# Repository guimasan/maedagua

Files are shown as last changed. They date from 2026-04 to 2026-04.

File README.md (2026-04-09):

# IARA V1 — Monitoramento de Qualidade da Água (Arduino Uno)

Projeto para aquisição de dados de **temperatura** e **TDS/condutividade estimada**, com transmissão serial, painel local e página pública para visualização em tempo real.

## Visão geral

O IARA V1 realiza:

- leitura de temperatura com **DS18B20**
- leitura analógica de **TDS** em `A1`
- exibição local em **OLED SSD1306 I2C (128x64)**
- envio contínuo de telemetria via **USB Serial**

O repositório inclui firmware, backend de painel e dashboard web para uso local e publicação.

## Estrutura do repositório

- `firmware/iara_arduino_uno_v1.ino` — firmware do Arduino Uno
- `_painel_iot_server/` — backend + dashboards locais
- `docs/index.html` — dashboard público (GitHub Pages)
- `docs/USO_RAPIDO.md` — guia curto de operação
- `tools/calibrar_tds.py` — calibração rápida via serial
- `tools/diagnostico_leituras.py` — diagnóstico comparativo de modos

## Arquitetura de dados

1. O Arduino coleta dados dos sensores.
2. A telemetria é enviada pela serial (`115200`).
3. O bridge (`_painel_iot_server/bridge_arduino.py`) converte e publica para a API.
4. Dashboards consomem API/WS para visualização em tempo real e histórico.

Exemplo de payload serial:

```text
DEVICE=iara-uno-0001;SEQ=1;TS_MS=1034;TEMP_C=25.19;TDS_PPM=131;TDS_ADC=287;TDS_V=1.404;TEMP_OK=1;TDS_OK=1;FW=1.0.0
```

## Equipamentos e sensores utilizados

- **Microcontrolador:** Arduino Uno (ATmega328P)
- **Temperatura:** DS18B20 (OneWire)
- **TDS/EC:** módulo TDS analógico compatível com entrada ADC do Uno
- **Display:** OLED SSD1306 I2C 128x64 (`0x3C`)
- **Conexão host:** USB serial

## Ligações elétricas (padrão do projeto)

- **DS18B20:** `D3`, `5V`, `GND`
- **TDS analógico:** `A1`, `5V`, `GND`
- **OLED SSD1306:** `SDA(A4)`, `SCL(A5)`, `5V`, `GND`

## Medidas, faixas e interpretação

### Temperatura (DS18B20)

- resolução configurável pelo sensor: 9–12 bits
- precisão típica de referência: aproximadamente $\pm 0.5\,^{\circ}C$ na faixa central de operação (ver datasheet)
- saída no projeto: `TEMP_C`

### TDS/EC (módulo analógico)

- leitura bruta no ADC de 10 bits do Uno (`0..1023`): `TDS_ADC`
- tensão estimada: `TDS_V`
- concentração estimada: `TDS_PPM`
- valor bruto antes de ganho de calibração: `TDS_RAW_PPM`

> Observação: TDS depende de temperatura, tipo de sonda, circuito e solução de referência. Tratar os valores como **medição estimada**, com calibração periódica.

## Calibração TDS

Campos publicados:

- `CAL` — estado da calibração
- `CAL_GAIN` — ganho aplicado
- `TDS_RAW_PPM` — base sem ganho

Estados de `CAL`:

- `0`: idle
- `1`: aguardando referência
- `2`: aplicado e não salvo
- `3`: salvo em EEPROM

Comandos serial:

- `CAL=ON`
- `CAL=APPLY:<ppm>`
- `CAL=SAVE`
- `CAL=RESET`
- `CAL=OFF`
- `CAL?`

Referência comum de condutividade:

- solução: **1413 µS/cm**
- escala 500: $ppm = EC \times 0.5$
- resultado: $1413 \times 0.5 = 706.5\,ppm$

Aplicação típica: `CAL=APPLY:706.5` seguido de `CAL=SAVE`.

## Modos de diagnóstico de leitura

Comandos para avaliar impacto de OLED e sequência de amostragem:

- `MODE=0` normal
- `MODE=1` pausa OLED durante leitura
- `MODE=2` OLED desligada durante leitura
- `MODE=3` OLED sempre desligada
- `MODE=4` leitura alternada por sensor
- consulta: `MODE?` ou `STATUS`

## Bibliotecas Arduino

- `OneWire`
- `DallasTemperature`
- `Adafruit GFX Library`
- `Adafruit SSD1306`

## Operação rápida

1. Gravar `firmware/iara_arduino_uno_v1.ino` no Arduino Uno.
2. Abrir monitor serial em `115200`.
3. Validar chegada de telemetria.
4. Opcional: executar scripts em `tools/` para diagnóstico/calibração.
5. Subir backend em `_painel_iot_server` para dashboard local e integração web.

## Dashboard público (GitHub Pages)

`docs/index.html` fornece:

- visualização em tempo real
- histórico cronológico
- detecção automática de variáveis
- seleção de endpoint da API

Para publicar:

1. Ativar GitHub Pages apontando para `main/docs`.
2. Abrir a página publicada.
3. Configurar a URL da API (preferencialmente HTTPS).

## Boas práticas de medição

- Aguarde estabilização térmica da amostra antes de registrar.
- Evite encostar a sonda nas paredes do recipiente.
- Faça agitação leve e padronizada da amostra.
- Registre temperatura junto com TDS para comparação entre coletas.
- Recalibre periodicamente com solução padrão conhecida.

## Referências técnicas

- Arduino Uno Rev3: https://docs.arduino.cc/hardware/uno-rev3
- ATmega328P (microcontrolador do Uno): https://www.microchip.com/en-us/product/ATmega328P
- DS18B20 (Maxim/Analog): https://www.analog.com/en/products/ds18b20.html
- Biblioteca DallasTemperature: https://github.com/milesburton/Arduino-Temperature-Control-Library
- Biblioteca OneWire (Paul Stoffregen): https://github.com/PaulStoffregen/OneWire
- Adafruit SSD1306: https://github.com/adafruit/Adafruit_SSD1306
- Adafruit GFX: https://github.com/adafruit/Adafruit-GFX-Library

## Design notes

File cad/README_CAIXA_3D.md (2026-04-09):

# Caixa 3D — IARA V1

Este diretório contém um modelo paramétrico em OpenSCAD para a caixa do sistema IARA V1.

## Arquivo

- `caixa_iara_v1.scad`

## Arquivos prontos para impressão

Já renderizados neste projeto:

- `cad/stl/caixa_iara_v1_base.stl`
- `cad/stl/caixa_iara_v1_tampa.stl`

Esses arquivos podem ser importados direto no slicer da sua impressora.

## Componentes previstos

- Arduino Uno
- Módulo TDS Keyestudio v1.0 (dimensões aproximadas)
- OLED 0.96" I2C
- Saída lateral para cabo do TDS
- Saída lateral para cabo do sensor de temperatura
- Recortes para USB-B e jack DC do Uno

## Saída do display (OLED) — revisão aplicada

A janela do display fica na **tampa superior** e agora é totalmente ajustável por parâmetros:

- `oled_margin_top` → distância da borda superior da tampa até o centro da janela
- `oled_offset_x` → deslocamento horizontal da janela

Também foram incluídos:

- postes internos para fixação do OLED (`lid_oled_posts`)
- canal para passagem do cabo do OLED (`oled_cable_notch_*`)

Se quiser mover a janela para alinhar exatamente ao seu módulo, ajuste esses dois parâmetros e gere apenas a tampa (`part = "lid"`) para teste rápido.

## Saídas dos cabos dos sensores (TDS e temperatura)

As saídas ficam na **lateral direita da base**.

Dimensões aplicadas no modelo:

- TDS (conector): retangular `5 x 7 mm` + folga
- Temperatura (cabo): circular `4 mm` + folga

Para visualizar facilmente no OpenSCAD, use:

- `part = "base"` ou `part = "assembled"`
- `show_cable_helpers = true`

Com isso, o modelo mostra guias verdes transparentes indicando o caminho dos furos. Essas guias são somente preview e **não entram no STL**.

## Como gerar STL

No OpenSCAD:

1. Abra `caixa_iara_v1.scad`
2. Ajuste `part` para:
   - `"base"` para exportar a base
   - `"lid"` para exportar a tampa
3. Renderize (`F6`)
4. Exporte STL

## Configuração inicial de impressão (FDM)

- Bico: 0.4 mm
- Altura de camada: 0.2 mm
- Paredes: 3 linhas
- Infill: 20–30%
- Material sugerido:
  - PLA para protótipo rápido
  - PETG para uso em ambiente úmido/externo
- Suportes: normalmente não necessários

## Perfil sugerido — Creality Hi + PETG Premium

Configuração inicial segura para começar (ajuste fino depois do primeiro teste):

- Bico: `0.4 mm`
- Altura de camada: `0.20 mm`
- Largura de linha: `0.42 mm`
- Paredes: `3`
- Top/Bottom: `5` camadas
- Infill: `25%` (Gyroid ou Grid)
- Temperatura do bico:
   - 1ª camada: `245 °C`
   - demais: `240 °C`
- Mesa:
   - 1ª camada: `80 °C`
   - demais: `75 °C`
- Ventoinha:
   - 1ª camada: `0%`
   - demais: `20–35%`
- Velocidade:
   - perímetro externo: `35 mm/s`
   - perímetro interno: `55 mm/s`
   - preenchimento: `70 mm/s`
- Retração (direct drive):
   - distância: `0.8 mm`
   - velocidade: `35 mm/s`
- Brim: `6 mm` (recomendado para PETG)

### Orientação das peças no slicer

- `caixa_iara_v1_base.stl`: imprimir com o fundo plano na mesa.
- `caixa_iara_v1_tampa.stl`: imprimir com a face externa da tampa voltada para a mesa.

### Material

Para PETG Premium, limpar mesa e aplicar adesão leve (cola bastão/spray apropriado) ajuda a evitar excesso de aderência na remoção.

## Parafusos recomendados

- Fixação de placas: parafuso M3 (autoatarraxante leve ou porca M3, conforme ajuste)
- Fechamento da tampa: M3 x 8 a M3 x 12

## Ajustes esperados (importante)

As dimensões do módulo TDS e do OLED podem variar entre lotes/fabricantes. Recomenda-se:

1. Medir sua placa real com paquímetro
2. Ajustar no SCAD os parâmetros:
   - `tds_x`, `tds_y`, `tds_holes`
   - `oled_*` (janela, furos, postes e canal de cabo)
3. Imprimir um teste rápido da tampa para validar a janela do OLED

## Observação

O modelo foi feito para ser fácil de ajustar em campo e prioriza montagem prática.

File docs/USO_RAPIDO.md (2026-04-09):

# Uso rápido

## Ligar

- DS18B20 no pino D3
- TDS no pino A1
- OLED I2C 128x64 em SDA(A4) e SCL(A5)
- Arduino Uno no USB

## Bibliotecas necessárias

- OneWire
- DallasTemperature
- Adafruit GFX Library
- Adafruit SSD1306

## Enviar o código

Abra:

- `firmware/iara_arduino_uno_v1.ino`

Depois envie para a placa.

## Ver os dados

Abra o monitor serial em:

- `115200`

Exemplo:

```text
DEVICE=iara-uno-0001;SEQ=1;TS_MS=1034;TEMP_C=25.19;TDS_PPM=131;TDS_ADC=287;TDS_V=1.404;TEMP_OK=1;TDS_OK=1;FW=1.0.0
```

Agora o payload inclui também:

- `TDS_RAW_PPM`
- `CAL`
- `CAL_GAIN`
- `DISP`

## Calibração rápida no Monitor Serial

1. Abra o Monitor Serial em `115200`
2. Envie `CAL=ON`
3. Com a sonda em solução padrão, envie o valor equivalente em ppm.
   - Exemplo para **1413 µS/cm** no padrão 500-scale: `CAL=APPLY:706.5`
4. Se estiver bom, envie `CAL=SAVE`
5. Para conferir, envie `CAL?`

## O que o notebook faz

Seu webapp pode:

- ler a porta serial
- sincronizar os dados
- salvar logs
- mostrar histórico
- fazer gráficos e alertas

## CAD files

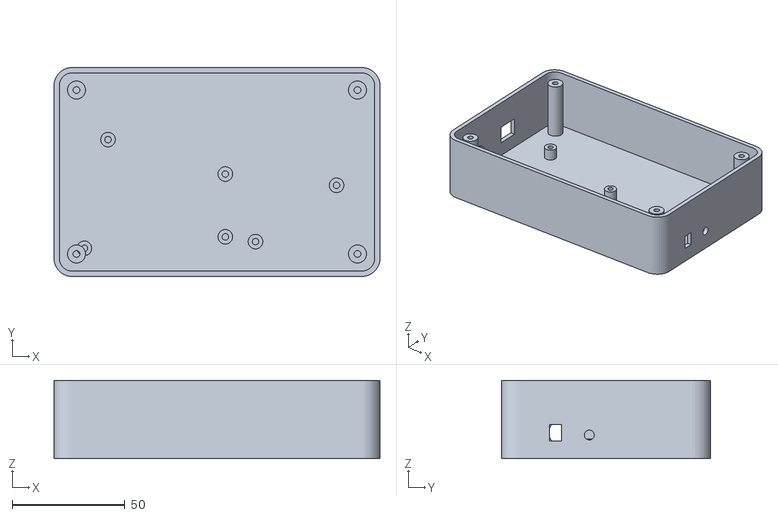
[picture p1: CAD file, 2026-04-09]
cad/stl/caixa_iara_v1_base.stl
144.8 x 92.8 x 34.8

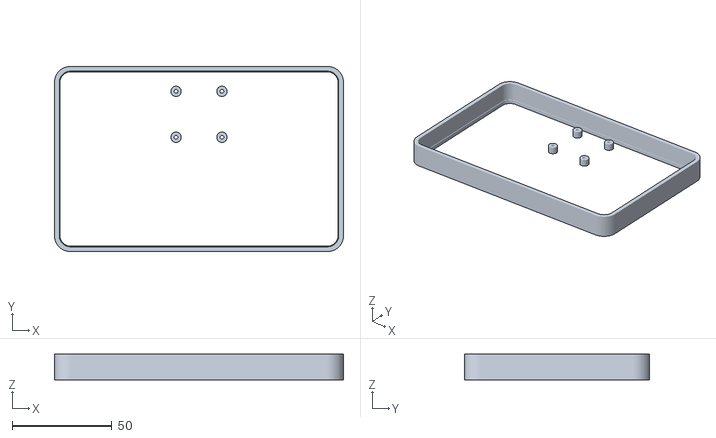
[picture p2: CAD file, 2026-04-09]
cad/stl/caixa_iara_v1_tampa.stl
144.8 x 92.8 x 13.0

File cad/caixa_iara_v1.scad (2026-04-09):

// IARA V1 - Caixa paramétrica (OpenSCAD)
// Componentes: Arduino Uno, módulo TDS Keyestudio v1.0, OLED 0.96" I2C
// Exportar com: part = "base" ou part = "lid"

$fn = 48;

// =====================
// Seleção de peça
// =====================
part = "assembled"; // "base", "lid", "assembled"
show_cable_helpers = true; // true = mostra guias visuais das saídas de cabo

// =====================
// Dimensões gerais (mm)
// =====================
wall = 2.4;
bottom = 2.8;
lid_thickness = 2.4;
clearance = 0.35;
corner_r = 8;

inner_x = 140;
inner_y = 88;
inner_z = 32; // altura útil interna da base

outer_x = inner_x + wall * 2;
outer_y = inner_y + wall * 2;
base_h = bottom + inner_z;
lid_h = 13;

// =====================
// Arduino Uno R3 (aprox.)
// =====================
uno_x = 68.6;
uno_y = 53.4;
uno_h = 14; // folga para componentes + headers
standoff_d = 6.5;
standoff_h = 6;
standoff_hole_d = 2.9; // para parafuso M3 autoatarraxante leve

// Furação aproximada (referência no canto da placa)
uno_holes = [
    [3.5, 2.5],
    [66.1, 7.6],
    [66.1, 35.5],
    [14.0, 50.8]
];

// posição da placa dentro da caixa
uno_pos = [10, 10, bottom];

// recortes laterais para USB-B e jack DC (lado esquerdo da caixa)
usb_cut = [13, 11.5, 9.5]; // x(profundidade), y(largura), z(altura)
usb_cut_pos = [0, uno_pos[1] + 36, 10.5];

jack_cut_d = 11;
jack_cut_pos = [0, uno_pos[1] + 16.5, 11.5];

// =====================
// Módulo TDS Keyestudio v1.0 (aprox.)
// =====================
tds_x = 43;
tds_y = 32;
tds_pos = [86, 12, bottom];
tds_holes = [
    [3.5, 3.5],
    [39.5, 28.5]
];

// =====================
// OLED 0.96" (módulo I2C 4 pinos)
// =====================
oled_board_x = 27.5;
oled_board_y = 27.5;
oled_hole_pitch_x = 23;
oled_hole_pitch_y = 23;
oled_screen_x = 23.5;
oled_screen_y = 13.5;

// Saída do display (janela) na tampa:
// - oled_margin_top maior = janela mais para baixo
// - oled_offset_x positivo = desloca para a direita
oled_margin_top = 24;
oled_offset_x = 0;
oled_center = [outer_x / 2 + oled_offset_x, outer_y - oled_margin_top];

// Ajustes de montagem da placa OLED na tampa
oled_hole_d = 2.4;
oled_post_d = 5.2;
oled_post_h = 4.0;
oled_post_hole_d = 1.9; // para parafuso M2/M2.2

// Canal para passagem dos fios do OLED (lado superior da tampa)
oled_cable_notch_w = 8;
oled_cable_notch_h = 4;

echo("OLED center XY:", oled_center);
echo("Ajuste saída display: oled_margin_top / oled_offset_x");

// =====================
// Saídas de cabo
// =====================
// Lado direito da base
cable_fit_clearance = 0.4; // folga geral para montagem/impressão

// TDS: conector retangular informado (5 x 7 mm)
cable_tds_w = 5 + cable_fit_clearance;
cable_tds_h = 7 + cable_fit_clearance;

// Temperatura: cabo circular de 4 mm
cable_temp_d = 4 + cable_fit_clearance;
cable_cut_depth = wall + 2.2; // profundidade para atravessar a parede com folga

// Nota: o eixo do cilindro está no +X após rotate([0,90,0]), então iniciamos em
// outer_x - cable_cut_depth para garantir corte completo na lateral direita.
// Para o TDS retangular usamos a mesma referência de centro em Y/Z
cable_tds_center_y = 24;
cable_tds_center_z = 11.5;
cable_tds_pos = [outer_x - cable_cut_depth, cable_tds_center_y - cable_tds_w / 2, cable_tds_center_z - cable_tds_h / 2];
cable_temp_pos = [outer_x - cable_cut_depth, 39, 10.5];

// =====================
// Parafusos da tampa
// =====================
post_d = 8;
post_hole_d = 3.0;
post_core_h = inner_z - 2;

post_xy = [
    [10, 10],
    [outer_x - 10, 10],
    [outer_x - 10, outer_y - 10],
    [10, outer_y - 10]
];

module rounded_box(x, y, z, r) {
    hull() {
        for (ix = [r, x - r])
            for (iy = [r, y - r])
                translate([ix, iy, 0]) cylinder(h = z, r = r);
    }
}

module shell_base() {
    difference() {
        rounded_box(outer_x, outer_y, base_h, corner_r);
        translate([wall, wall, bottom])
            rounded_box(inner_x, inner_y, inner_z + 0.2, max(corner_r - wall, 1));
    }
}

module lid_shell() {
    difference() {
        rounded_box(outer_x, outer_y, lid_h, corner_r);

        // cavidade da tampa
        translate([wall, wall, lid_thickness])
            rounded_box(inner_x, inner_y, lid_h, max(corner_r - wall, 1));

        // aba de encaixe
        translate([wall + clearance, wall + clearance, 0])
            rounded_box(inner_x - 2 * clearance, inner_y - 2 * clearance, 8, max(corner_r - wall - clearance, 1));

        // remover centro da aba
        translate([wall + 2.2, wall + 2.2, 0])
            rounded_box(inner_x - 4.4, inner_y - 4.4, 8.1, max(corner_r - wall - 2.2, 1));
    }
}

module board_standoffs(origin, holes) {
    for (h = holes) {
        translate([origin[0] + h[0], origin[1] + h[1], origin[2]])
            difference() {
                cylinder(h = standoff_h, d = standoff_d);
                translate([0, 0, -0.1]) cylinder(h = standoff_h + 0.2, d = standoff_hole_d);
            }
    }
}

module lid_posts_for_screws() {
    for (p = post_xy) {
        translate([p[0], p[1], bottom])
            difference() {
                cylinder(h = post_core_h, d = post_d);
                translate([0, 0, -0.1]) cylinder(h = post_core_h + 0.2, d = post_hole_d);
            }
    }
}

module cable_holes() {
    // TDS
    translate(cable_tds_pos)
        cube([cable_cut_depth, cable_tds_w, cable_tds_h]);

    // Temperatura
    translate(cable_temp_pos)
        rotate([0, 90, 0]) cylinder(h = cable_cut_depth, d = cable_temp_d);
}

module cable_holes_helper() {
    if (show_cable_helpers) {
        // Preview only (%): visível no editor, não exporta para STL
        %color([0.2, 0.9, 0.3, 0.45])
            translate(cable_tds_pos)
                cube([cable_cut_depth, cable_tds_w, cable_tds_h]);
        %color([0.2, 0.9, 0.3, 0.45])
            translate(cable_temp_pos)
                rotate([0, 90, 0]) cylinder(h = cable_cut_depth, d = cable_temp_d);
    }
}

module uno_side_ports() {
    // USB-B
    translate([usb_cut_pos[0] - 0.5, usb_cut_pos[1], usb_cut_pos[2]])
        cube([usb_cut[0] + 1, usb_cut[1], usb_cut[2]]);

    // Jack DC
    translate([jack_cut_pos[0] - 0.5, jack_cut_pos[1], jack_cut_pos[2]])
        rotate([0, 90, 0]) cylinder(h = wall + 1.5, d = jack_cut_d);
}

module lid_oled_window_and_holes() {
    // Janela do display
    translate([oled_center[0] - oled_screen_x / 2, oled_center[1] - oled_screen_y / 2, -0.2])
        cube([oled_screen_x, oled_screen_y, lid_thickness + 0.6]);

    // Furos da placa OLED
    for (sx = [-oled_hole_pitch_x / 2, oled_hole_pitch_x / 2])
        for (sy = [-oled_hole_pitch_y / 2, oled_hole_pitch_y / 2])
            translate([oled_center[0] + sx, oled_center[1] + sy, -0.2])
                cylinder(h = lid_thickness + 1.2, d = oled_hole_d);

    // Canal de saída do cabo do OLED (da região dos pinos para dentro da caixa)
    translate([oled_center[0] - oled_cable_notch_w / 2, oled_center[1] + oled_hole_pitch_y / 2 - 1, -0.2])
        cube([oled_cable_notch_w, oled_cable_notch_h, lid_thickness + 0.8]);
}

module lid_oled_posts() {
    // Postes de apoio/fixação da placa OLED na face interna da tampa
    for (sx = [-oled_hole_pitch_x / 2, oled_hole_pitch_x / 2])
        for (sy = [-oled_hole_pitch_y / 2, oled_hole_pitch_y / 2])
            translate([oled_center[0] + sx, oled_center[1] + sy, lid_thickness])
                difference() {
                    cylinder(h = oled_post_h, d = oled_post_d);
                    translate([0, 0, -0.1]) cylinder(h = oled_post_h + 0.2, d = oled_post_hole_d);
                }
}

module lid_screw_holes() {
    for (p = post_xy) {
        translate([p[0], p[1], -0.2])
            cylinder(h = lid_h + 0.4, d = 3.4);

        // rebaixo para cabeça do parafuso
        translate([p[0], p[1], lid_h - 2.2])
            cylinder(h = 2.5, d = 6.2);
    }
}

module base_part() {
    difference() {
        shell_base();
        cable_holes();
        uno_side_ports();
    }

    // Standoffs Arduino
    board_standoffs(uno_pos, uno_holes);

    // Standoffs TDS
    board_standoffs(tds_pos, tds_holes);

    // Postes para parafusos da tampa
    lid_posts_for_screws();
}

module lid_part() {
    union() {
        difference() {
            lid_shell();
            lid_oled_window_and_holes();
            lid_screw_holes();
        }
        lid_oled_posts();
    }
}

if (part == "base") {
    base_part();
    cable_holes_helper();
}

if (part == "lid") {
    lid_part();
}

if (part == "assembled") {
    color("#1f2937") base_part();
    cable_holes_helper();
    translate([0, 0, base_h + 0.2]) color("#334155") lid_part();
}

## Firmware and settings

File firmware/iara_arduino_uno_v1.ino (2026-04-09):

/*
  MaeDagua - Arduino Uno V1

  Função deste sketch:
  - ler temperatura no DS18B20 (D3)
  - ler TDS no A1
  - enviar dados pela USB Serial

  O notebook/webapp pode ler essa serial,
  sincronizar e guardar logs quando quiser.

  Formato enviado:
  DEVICE=iara-uno-0001;SEQ=1;TS_MS=1034;TEMP_C=25.19;TDS_PPM=131;TDS_ADC=287;TDS_V=1.404;TEMP_OK=1;TDS_OK=1;FW=1.0.0
*/

#include <OneWire.h>
#include <DallasTemperature.h>
#include <Wire.h>
#include <Adafruit_GFX.h>
#include <Adafruit_SSD1306.h>
#include <EEPROM.h>

const int PIN_TEMP_SENSOR = 3;
const int PIN_TDS_SENSOR = A1;
const char* DEVICE_ID = "iara-uno-0001";
const char* FW_VERSION = "1.5.0";

const int OLED_WIDTH = 128;
const int OLED_HEIGHT = 64;
const int OLED_RESET_PIN = -1;
const uint8_t OLED_I2C_ADDR = 0x3C;

OneWire oneWireBus(PIN_TEMP_SENSOR);
DallasTemperature temperatureSensors(&oneWireBus);
Adafruit_SSD1306 oled(OLED_WIDTH, OLED_HEIGHT, &Wire, OLED_RESET_PIN);

const unsigned long SEND_INTERVAL_MS = 1000;
unsigned long lastSendAtMs = 0;
unsigned long packetSequence = 0;
const unsigned long OLED_PAGE_INTERVAL_MS = 5000;
const unsigned long OLED_TRANSITION_MS = 900;
const unsigned long OLED_REFRESH_MS = 80;
const int SERIAL_CMD_BUFFER_SIZE = 32;

const float TDS_CALIBRATION_FACTOR = 0.5;
const int TDS_SAMPLES = 20;
const int TDS_SAMPLE_DELAY_MS = 2;
const float TDS_MIN_RAW_PPM_FOR_CAL = 5.0;

const int EEPROM_ADDR_MAGIC = 0;
const int EEPROM_ADDR_TDS_GAIN = EEPROM_ADDR_MAGIC + sizeof(uint16_t);
const uint16_t EEPROM_CAL_MAGIC = 0xC411;

bool isOledReady = false;

enum CalState {
  CAL_STATE_IDLE = 0,
  CAL_STATE_WAIT_REFERENCE = 1,
  CAL_STATE_APPLIED_NOT_SAVED = 2,
  CAL_STATE_SAVED = 3
};

uint8_t calibrationState = CAL_STATE_IDLE;
float tdsCalibrationGain = 1.0;

enum ReadMode {
  READ_MODE_NORMAL = 0,
  READ_MODE_PAUSE_OLED_DURING_READ = 1,
  READ_MODE_DISPLAY_OFF_DURING_READ = 2,
  READ_MODE_OLED_DISABLED = 3,
  READ_MODE_ALTERNATE_SENSORS = 4,
  READ_MODE_COUNT
};

uint8_t currentReadMode = READ_MODE_NORMAL;
bool isSensorReadInProgress = false;
bool nextAlternateReadIsTemp = true;
char serialCmdBuffer[SERIAL_CMD_BUFFER_SIZE];
uint8_t serialCmdPos = 0;

enum DisplayMode {
  DISPLAY_MODE_ROTATING = 0,
  DISPLAY_MODE_SINGLE_SCREEN = 1
};

uint8_t currentDisplayMode = DISPLAY_MODE_ROTATING;

enum OledPage {
  OLED_PAGE_TEMP = 0,
  OLED_PAGE_TDS_PPM,
  OLED_PAGE_TDS_VOLTAGE,
  OLED_PAGE_FISH,
  OLED_PAGE_COUNT
};

uint8_t currentOledPage = OLED_PAGE_TEMP;
unsigned long oledPageStartedAtMs = 0;
unsigned long lastOledRefreshAtMs = 0;
bool isTransitionActive = false;
unsigned long transitionStartedAtMs = 0;

bool latestTempOk = false;
float latestTempC = NAN;
int latestTdsAdc = 0;
float latestRawTdsPpm = 0;
float latestTdsVoltage = 0;
float latestTdsPpm = 0;
bool hasSensorData = false;
float lastValidTempC = 0;
bool hasLastValidTemp = false;
bool tempSampledThisCycle = false;
bool tdsSampledThisCycle = false;

float readTemperatureCelsius(bool &ok) {
  temperatureSensors.requestTemperatures();
  float value = temperatureSensors.getTempCByIndex(0);
  ok = (value != DEVICE_DISCONNECTED_C);
  return ok ? value : NAN;
}

int readTdsMedianAdc() {
  int samples[TDS_SAMPLES];

  for (int i = 0; i < TDS_SAMPLES; i++) {
    samples[i] = analogRead(PIN_TDS_SENSOR);
    delay(TDS_SAMPLE_DELAY_MS);
  }

  for (int i = 0; i < TDS_SAMPLES - 1; i++) {
    for (int j = i + 1; j < TDS_SAMPLES; j++) {
      if (samples[j] < samples[i]) {
        int aux = samples[i];
        samples[i] = samples[j];
        samples[j] = aux;
      }
    }
  }

  return samples[TDS_SAMPLES / 2];
}

float convertAdcToVoltage(int adc) {
  return adc * (5.0 / 1023.0);
}

float convertAdcToTdsPpm(int adc) {
  float voltage = convertAdcToVoltage(adc);
  float tds = (voltage - 0.15) * TDS_CALIBRATION_FACTOR * 1000.0;
  if (tds < 0) tds = 0;
  return tds;
}

void loadCalibrationFromEeprom() {
  uint16_t magic = 0;
  float gain = 1.0;
  EEPROM.get(EEPROM_ADDR_MAGIC, magic);
  EEPROM.get(EEPROM_ADDR_TDS_GAIN, gain);

  if (magic == EEPROM_CAL_MAGIC && gain > 0.05 && gain < 20.0) {
    tdsCalibrationGain = gain;
    calibrationState = CAL_STATE_SAVED;
  } else {
    tdsCalibrationGain = 1.0;
    calibrationState = CAL_STATE_IDLE;
  }
}

void saveCalibrationToEeprom() {
  EEPROM.put(EEPROM_ADDR_MAGIC, EEPROM_CAL_MAGIC);
  EEPROM.put(EEPROM_ADDR_TDS_GAIN, tdsCalibrationGain);
  calibrationState = CAL_STATE_SAVED;
}

void resetCalibration() {
  tdsCalibrationGain = 1.0;
  EEPROM.put(EEPROM_ADDR_MAGIC, (uint16_t)0);
  EEPROM.put(EEPROM_ADDR_TDS_GAIN, tdsCalibrationGain);
  calibrationState = CAL_STATE_IDLE;
}

void setOledPower(bool on) {
  if (!isOledReady) {
    return;
  }
  oled.ssd1306_command(on ? SSD1306_DISPLAYON : SSD1306_DISPLAYOFF);
}

void applyReadMode(uint8_t mode) {
  if (mode >= READ_MODE_COUNT) {
    return;
  }

  currentReadMode = mode;
  nextAlternateReadIsTemp = true;

  if (currentReadMode == READ_MODE_OLED_DISABLED) {
    setOledPower(false);
  } else {
    setOledPower(true);
    oledPageStartedAtMs = millis();
    transitionStartedAtMs = millis();
    isTransitionActive = false;
  }

  Serial.print(F("MODE_SET="));
  Serial.println(currentReadMode);
}

void applyDisplayMode(uint8_t mode) {
  if (mode > DISPLAY_MODE_SINGLE_SCREEN) {
    return;
  }

  currentDisplayMode = mode;
  oledPageStartedAtMs = millis();
  transitionStartedAtMs = millis();
  isTransitionActive = false;

  Serial.print(F("DISP_SET="));
  Serial.println(currentDisplayMode);
}

void printCalibrationStatus() {
  Serial.print(F("CAL="));
  Serial.print(calibrationState);
  Serial.print(F(";CAL_GAIN="));
  Serial.println(tdsCalibrationGain, 5);
}

void processSerialCommand(const char* cmdRaw) {
  if (strncmp(cmdRaw, "MODE=", 5) == 0) {
    int mode = atoi(cmdRaw + 5);
    if (mode >= 0 && mode < READ_MODE_COUNT) {
      applyReadMode((uint8_t)mode);
    } else {
      Serial.println(F("ERR=MODE_INVALID"));
    }
    return;
  }

  if (strncmp(cmdRaw, "DISP=", 5) == 0) {
    int mode = atoi(cmdRaw + 5);
    if (mode >= 0 && mode <= DISPLAY_MODE_SINGLE_SCREEN) {
      applyDisplayMode((uint8_t)mode);
    } else {
      Serial.println(F("ERR=DISP_INVALID"));
    }
    return;
  }

  if (strcmp(cmdRaw, "CAL=ON") == 0) {
    calibrationState = CAL_STATE_WAIT_REFERENCE;
    Serial.println(F("CAL_MODE=WAIT_REFERENCE"));
    printCalibrationStatus();
    return;
  }

  if (strcmp(cmdRaw, "CAL=OFF") == 0) {
    calibrationState = CAL_STATE_IDLE;
    Serial.println(F("CAL_MODE=OFF"));
    printCalibrationStatus();
    return;
  }

  if (strncmp(cmdRaw, "CAL=APPLY:", 10) == 0) {
    float referencePpm = atof(cmdRaw + 10);
    if (referencePpm <= 0) {
      Serial.println(F("ERR=CAL_REFERENCE_INVALID"));
      return;
    }
    if (latestRawTdsPpm < TDS_MIN_RAW_PPM_FOR_CAL) {
      Serial.println(F("ERR=CAL_RAW_TOO_LOW"));
      return;
    }

    tdsCalibrationGain = referencePpm / latestRawTdsPpm;
    if (tdsCalibrationGain < 0.05 || tdsCalibrationGain > 20.0) {
      Serial.println(F("ERR=CAL_GAIN_OUT_OF_RANGE"));
      tdsCalibrationGain = 1.0;
      calibrationState = CAL_STATE_IDLE;
      return;
    }

    calibrationState = CAL_STATE_APPLIED_NOT_SAVED;
    Serial.print(F("CAL_APPLIED_REF="));
    Serial.println(referencePpm, 2);
    printCalibrationStatus();
    return;
  }

  if (strcmp(cmdRaw, "CAL=SAVE") == 0) {
    saveCalibrationToEeprom();
    Serial.println(F("CAL_SAVED=1"));
    printCalibrationStatus();
    return;
  }

  if (strcmp(cmdRaw, "CAL=RESET") == 0) {
    resetCalibration();
    Serial.println(F("CAL_RESET=1"));
    printCalibrationStatus();
    return;
  }

  if (strcmp(cmdRaw, "MODE?") == 0 || strcmp(cmdRaw, "STATUS") == 0) {
    Serial.print(F("MODE="));
    Serial.println(currentReadMode);
    Serial.print(F("DISP="));
    Serial.println(currentDisplayMode);
    printCalibrationStatus();
    return;
  }

  if (strcmp(cmdRaw, "DISP?") == 0) {
    Serial.print(F("DISP="));
    Serial.println(currentDisplayMode);
    return;
  }

  if (strcmp(cmdRaw, "CAL?") == 0) {
    printCalibrationStatus();
    return;
  }

  if (strcmp(cmdRaw, "HELP") == 0) {
    Serial.println(F("CMD: MODE=0..4 | DISP=0..1 | CAL=ON|OFF|APPLY:ppm|SAVE|RESET | MODE? | DISP? | CAL? | STATUS | HELP"));
    return;
  }

  Serial.println(F("ERR=CMD_UNKNOWN"));
}

void handleSerialCommands() {
  while (Serial.available() > 0) {
    char c = (char)Serial.read();

    if (c == '\r') {
      continue;
    }

    if (c == '\n') {
      if (serialCmdPos > 0) {
        serialCmdBuffer[serialCmdPos] = '\0';
        processSerialCommand(serialCmdBuffer);
        serialCmdPos = 0;
      }
      continue;
    }

    if (serialCmdPos < SERIAL_CMD_BUFFER_SIZE - 1) {
      serialCmdBuffer[serialCmdPos++] = c;
    }
  }
}

void formatFloatValue(char* out, size_t outSize, float value, uint8_t decimals, const char* suffix) {
  char number[16];
  dtostrf(value, 0, decimals, number);
  snprintf(out, outSize, "%s%s", number, suffix);
}

void drawCenteredText(const char* text, int y, uint8_t size) {
  int16_t x1, y1;
  uint16_t width, height;
  oled.setTextSize(size);
  oled.getTextBounds(text, 0, y, &x1, &y1, &width, &height);
  int16_t x = (OLED_WIDTH - (int16_t)width) / 2;
  if (x < 0) x = 0;
  oled.setCursor(x, y);
  oled.print(text);
}

void drawValuePage(const __FlashStringHelper* title, const char* value) {
  oled.clearDisplay();
  oled.setTextColor(SSD1306_WHITE);
  oled.setTextSize(1);
  oled.setCursor(0, 0);
  oled.print(title);
  drawCenteredText(value, 22, 3);
  oled.display();
}

void drawFishAnimationPage(unsigned long elapsedInPageMs) {
  oled.clearDisplay();
  oled.setTextColor(SSD1306_WHITE);
  oled.setTextSize(1);
  oled.setCursor(0, 0);
  oled.print(F("IARA"));

  int travel = OLED_WIDTH + 30;
  int fishX = OLED_WIDTH - ((int)((elapsedInPageMs * travel) / OLED_PAGE_INTERVAL_MS));
  int fishY = 34 + (((elapsedInPageMs / 150) % 2) ? 3 : -3);

  oled.fillCircle(fishX, fishY, 8, SSD1306_WHITE);
  oled.fillTriangle(fishX + 8, fishY, fishX + 16, fishY - 5, fishX + 16, fishY + 5, SSD1306_WHITE);
  oled.fillCircle(fishX - 3, fishY - 2, 1, SSD1306_BLACK);

  int bubbleX = fishX - 16;
  int bubbleY = fishY - (int)((elapsedInPageMs / 80) % 20);
  oled.drawCircle(bubbleX, bubbleY, 2, SSD1306_WHITE);
  oled.drawCircle(bubbleX - 6, bubbleY - 8, 1, SSD1306_WHITE);

  oled.display();
}

void drawWaterTransition(unsigned long elapsedTransitionMs) {
  oled.clearDisplay();
  oled.setTextColor(SSD1306_WHITE);
  oled.setTextSize(1);
  oled.setCursor(0, 0);
  oled.print(F("IARA"));

  int phase = (elapsedTransitionMs / 80) % 8;
  for (int x = 0; x < OLED_WIDTH; x += 8) {
    int offset = ((x / 8 + phase) % 2 == 0) ? 0 : 2;
    oled.drawLine(x, 16 + offset, x + 7, 16 + (2 - offset), SSD1306_WHITE);
    oled.drawLine(x, 22 + (2 - offset), x + 7, 22 + offset, SSD1306_WHITE);
  }

  int level = map((int)elapsedTransitionMs, 0, (int)OLED_TRANSITION_MS, OLED_HEIGHT + 4, 24);
  if (level < 24) level = 24;
  if (level > OLED_HEIGHT) level = OLED_HEIGHT;
  oled.fillRect(0, level, OLED_WIDTH, OLED_HEIGHT - level, SSD1306_WHITE);

  int bubbleStep = (elapsedTransitionMs / 60) % 10;
  for (int i = 0; i < 4; i++) {
    int bx = 18 + i * 28;
    int by = OLED_HEIGHT - ((bubbleStep * 3 + i * 5) % 30);
    if (by > level + 2) {
      oled.drawCircle(bx, by, 2, SSD1306_BLACK);
    }
  }

  oled.display();
}

void drawSingleScreenOverview() {
  oled.clearDisplay();
  oled.setTextColor(SSD1306_WHITE);
  oled.setTextSize(1);

  oled.setCursor(0, 0);
  oled.print(F("IARA ONE-SCREEN"));

  oled.setCursor(0, 14);
  oled.print(F("Temp: "));
  if (latestTempOk) {
    oled.print(latestTempC, 2);
    oled.print(F(" C"));
  } else {
    oled.print(F("OFF"));
  }

  oled.setCursor(0, 26);
  oled.print(F("TDS : "));
  oled.print(latestTdsPpm, 1);
  oled.print(F(" ppm"));

  oled.setCursor(0, 38);
  oled.print(F("TDS Volt.: "));
  oled.print(latestTdsVoltage, 3);
  oled.print(F(" V"));

  oled.setCursor(0, 50);
  oled.print(F("Mode "));
  oled.print(currentReadMode);
  oled.print(F(" / Disp "));
  oled.print(currentDisplayMode);

  oled.setCursor(0, 58);
  oled.print(F("CAL "));
  oled.print(calibrationState);
  oled.print(F(" G"));
  oled.print(tdsCalibrationGain, 2);

  oled.display();
}

void updateOledPresentation(unsigned long nowMs) {
  if (!isOledReady || currentReadMode == READ_MODE_OLED_DISABLED) {
    return;
  }

  if (isSensorReadInProgress && currentReadMode == READ_MODE_PAUSE_OLED_DURING_READ) {
    return;
  }

  if (currentDisplayMode == DISPLAY_MODE_SINGLE_SCREEN) {
    if (nowMs - lastOledRefreshAtMs < OLED_REFRESH_MS) {
      return;
    }
    lastOledRefreshAtMs = nowMs;

    if (!hasSensorData) {
      drawValuePage(F("AGUARDE DADOS"), "...");
      return;
    }

    drawSingleScreenOverview();
    return;
  }

  if (!isTransitionActive && (nowMs - oledPageStartedAtMs >= OLED_PAGE_INTERVAL_MS)) {
    isTransitionActive = true;
    transitionStartedAtMs = nowMs;
  }

  if (isTransitionActive && (nowMs - transitionStartedAtMs >= OLED_TRANSITION_MS)) {
    isTransitionActive = false;
    currentOledPage = (currentOledPage + 1) % OLED_PAGE_COUNT;
    oledPageStartedAtMs = nowMs;
  }

  if (nowMs - lastOledRefreshAtMs < OLED_REFRESH_MS) {
    return;
  }
  lastOledRefreshAtMs = nowMs;

  if (isTransitionActive) {
    drawWaterTransition(nowMs - transitionStartedAtMs);
    return;
  }

  if (!hasSensorData && currentOledPage != OLED_PAGE_FISH) {
    drawValuePage(F("AGUARDE DADOS"), "...");
    return;
  }

  char valueText[22];
  switch (currentOledPage) {
    case OLED_PAGE_TEMP:
      if (latestTempOk) {
        formatFloatValue(valueText, sizeof(valueText), latestTempC, 1, " C");
      } else {
        snprintf(valueText, sizeof(valueText), "SENSOR OFF");
      }
      drawValuePage(F("TEMPERATURA"), valueText);
      break;

    case OLED_PAGE_TDS_PPM:
      formatFloatValue(valueText, sizeof(valueText), latestTdsPpm, 0, " PPM");
      drawValuePage(F("TDS"), valueText);
      break;

    case OLED_PAGE_TDS_VOLTAGE:
      formatFloatValue(valueText, sizeof(valueText), latestTdsVoltage, 2, " V");
      drawValuePage(F("TDS Volt."), valueText);
      break;

    case OLED_PAGE_FISH:
      drawFishAnimationPage(nowMs - oledPageStartedAtMs);
      break;
  }
}

void setup() {
  Serial.begin(115200);
  delay(800);
  temperatureSensors.begin();
  pinMode(PIN_TDS_SENSOR, INPUT);
  loadCalibrationFromEeprom();

  isOledReady = oled.begin(SSD1306_SWITCHCAPVCC, OLED_I2C_ADDR);
  if (isOledReady) {
    oled.clearDisplay();
    oled.setTextColor(SSD1306_WHITE);
    oled.setTextSize(1);
    oled.setCursor(0, 0);
    oled.println(F("MaeDagua iniciando"));
    oled.setCursor(0, 12);
    oled.println(DEVICE_ID);
    oled.setCursor(0, 24);
    oled.print(F("FW "));
    oled.println(FW_VERSION);
    oled.display();

    oledPageStartedAtMs = millis();
    lastOledRefreshAtMs = 0;
  }

  Serial.println(F("MaeDagua - Arduino Uno pronto"));
  Serial.println(F("DS18B20 em D3 | TDS em A1 | OLED I2C 0x3C | USB Serial"));
  Serial.println(isOledReady ? F("OLED: OK") : F("OLED: nao detectada"));
  Serial.println(F("Use MODE=0..4 para testes"));
  Serial.println(F("Use DISP=0 rotativo | DISP=1 tela unica"));
  Serial.println(F("Use CAL=ON|APPLY:ppm|SAVE|RESET"));
  printCalibrationStatus();
}

void loop() {
  unsigned long nowMs = millis();
  handleSerialCommands();

  if (millis() - lastSendAtMs >= SEND_INTERVAL_MS) {
    lastSendAtMs = nowMs;
    packetSequence++;

    isSensorReadInProgress = true;
    if (currentReadMode == READ_MODE_DISPLAY_OFF_DURING_READ) {
      setOledPower(false);
    }

    tempSampledThisCycle = false;
    tdsSampledThisCycle = false;

    bool tempOk = false;
    float tempC = latestTempC;
    int tdsAdc = latestTdsAdc;

    bool readTempNow = true;
    bool readTdsNow = true;
    if (currentReadMode == READ_MODE_ALTERNATE_SENSORS) {
      if (!hasSensorData) {
        readTempNow = true;
        readTdsNow = true;
      } else if (nextAlternateReadIsTemp) {
        readTempNow = true;
        readTdsNow = false;
      } else {
        readTempNow = false;
        readTdsNow = true;
      }
      nextAlternateReadIsTemp = !nextAlternateReadIsTemp;
    }

    if (readTempNow) {
      tempC = readTemperatureCelsius(tempOk);
      tempSampledThisCycle = true;
    } else {
      tempOk = hasLastValidTemp;
    }

    if (readTdsNow) {
      tdsAdc = readTdsMedianAdc();
      tdsSampledThisCycle = true;
    }

    float tdsV = convertAdcToVoltage(tdsAdc);
    float rawTdsPpm = convertAdcToTdsPpm(tdsAdc);
    float tdsPpm = rawTdsPpm * tdsCalibrationGain;
    if (tdsPpm < 0) tdsPpm = 0;
    unsigned long uptimeMs = nowMs;

    if (tempOk) {
      lastValidTempC = tempC;
      hasLastValidTemp = true;
    }

    float tempToSendC = (tempOk || !hasLastValidTemp) ? tempC : lastValidTempC;
    bool tempValueAvailable = tempOk || hasLastValidTemp;

    latestTempOk = tempValueAvailable;
    latestTempC = tempToSendC;
    latestTdsAdc = tdsAdc;
    latestRawTdsPpm = rawTdsPpm;
    latestTdsVoltage = tdsV;
    latestTdsPpm = tdsPpm;
    hasSensorData = true;

    if (currentReadMode == READ_MODE_DISPLAY_OFF_DURING_READ) {
      setOledPower(true);
    }
    isSensorReadInProgress = false;

    Serial.print(F("DEVICE="));
    Serial.print(DEVICE_ID);
    Serial.print(F(";SEQ="));
    Serial.print(packetSequence);
    Serial.print(F(";TS_MS="));
    Serial.print(uptimeMs);
    Serial.print(F(";TEMP_C="));
    if (tempValueAvailable) Serial.print(tempToSendC, 2);
    else Serial.print(F("NaN"));
    Serial.print(F(";TDS_PPM="));
    Serial.print(tdsPpm, 1);
    Serial.print(F(";TDS_RAW_PPM="));
    Serial.print(rawTdsPpm, 1);
    Serial.print(F(";TDS_ADC="));
    Serial.print(tdsAdc);
    Serial.print(F(";TDS_V="));
    Serial.print(tdsV, 3);
    Serial.print(F(";TEMP_OK="));
    Serial.print(tempOk ? 1 : 0);
    Serial.print(F(";TEMP_SAMPLE="));
    Serial.print(tempSampledThisCycle ? 1 : 0);
    Serial.print(F(";TDS_SAMPLE="));
    Serial.print(tdsSampledThisCycle ? 1 : 0);
    Serial.print(F(";MODE="));
    Serial.print(currentReadMode);
    Serial.print(F(";DISP="));
    Serial.print(currentDisplayMode);
    Serial.print(F(";CAL="));
    Serial.print(calibrationState);
    Serial.print(F(";CAL_GAIN="));
    Serial.print(tdsCalibrationGain, 5);
    Serial.print(F(";TDS_OK=1;FW="));
    Serial.println(FW_VERSION);
  }

  updateOledPresentation(nowMs);
}

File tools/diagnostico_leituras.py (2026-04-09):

#!/usr/bin/env python3
"""
Diagnóstico de leitura para o firmware MaeDagua.

Compara estabilidade de TEMP_C e TDS_PPM em diferentes modos:
  0 = normal
  1 = pausa OLED durante leitura
  2 = display OFF durante leitura
  3 = OLED desabilitada
  4 = sensores alternados (um por ciclo)

Uso rápido:
  python3 tools/diagnostico_leituras.py --port /dev/ttyUSB0 --seconds 40
"""

import argparse
import statistics
import time
from typing import Dict, List, Tuple

import serial


MODE_NAMES = {
    0: "normal",
    1: "pausa_oled_durante_leitura",
    2: "oled_off_durante_leitura",
    3: "oled_desligada",
    4: "sensores_alternados",
}


def parse_payload(line: str) -> Dict[str, str]:
    data: Dict[str, str] = {}
    for part in line.strip().split(";"):
        if "=" in part:
            key, value = part.split("=", 1)
            data[key] = value
    return data


def as_float(value: str):
    if value is None:
        return None
    try:
        if value.upper() == "NAN":
            return None
        return float(value)
    except Exception:
        return None


def summarize(values: List[float]) -> Dict[str, float]:
    if not values:
        return {"count": 0, "min": None, "max": None, "mean": None, "stdev": None}
    return {
        "count": len(values),
        "min": min(values),
        "max": max(values),
        "mean": statistics.mean(values),
        "stdev": statistics.pstdev(values) if len(values) > 1 else 0.0,
    }


def run_mode_test(ser: serial.Serial, mode: int, seconds: int, warmup: float) -> Dict[str, object]:
    ser.reset_input_buffer()
    ser.write(f"MODE={mode}\n".encode())
    ser.flush()

    # Aguarda ACK e estabilização curta.
    t0 = time.time()
    while time.time() - t0 < warmup:
        ser.readline()

    end_at = time.time() + seconds
    raw_lines = 0
    temp_values: List[float] = []
    tds_values: List[float] = []
    temp_ok_count = 0
    temp_sample_count = 0
    tds_sample_count = 0

    while time.time() < end_at:
        line = ser.readline().decode(errors="ignore").strip()
        if not line or not line.startswith("DEVICE="):
            continue

        raw_lines += 1
        payload = parse_payload(line)

        temp = as_float(payload.get("TEMP_C"))
        tds = as_float(payload.get("TDS_PPM"))

        if temp is not None:
            temp_values.append(temp)
        if tds is not None:
            tds_values.append(tds)

        if payload.get("TEMP_OK") == "1":
            temp_ok_count += 1
        if payload.get("TEMP_SAMPLE") == "1":
            temp_sample_count += 1
        if payload.get("TDS_SAMPLE") == "1":
            tds_sample_count += 1

    return {
        "mode": mode,
        "mode_name": MODE_NAMES.get(mode, "desconhecido"),
        "lines": raw_lines,
        "temp_stats": summarize(temp_values),
        "tds_stats": summarize(tds_values),
        "temp_ok_ratio": (temp_ok_count / raw_lines) if raw_lines else 0.0,
        "temp_sample_ratio": (temp_sample_count / raw_lines) if raw_lines else 0.0,
        "tds_sample_ratio": (tds_sample_count / raw_lines) if raw_lines else 0.0,
    }


def print_result(result: Dict[str, object]):
    t = result["temp_stats"]
    d = result["tds_stats"]

    print(f"\n=== MODO {result['mode']} ({result['mode_name']}) ===")
    print(f"linhas: {result['lines']}")
    print(
        "TEMP_C -> "
        f"n={t['count']} min={t['min']} max={t['max']} media={t['mean']} desvio={t['stdev']} "
        f"temp_ok={result['temp_ok_ratio']:.2%} temp_sample={result['temp_sample_ratio']:.2%}"
    )
    print(
        "TDS_PPM -> "
        f"n={d['count']} min={d['min']} max={d['max']} media={d['mean']} desvio={d['stdev']} "
        f"tds_sample={result['tds_sample_ratio']:.2%}"
    )


def pick_recommendation(results: List[Dict[str, object]]) -> Tuple[int, str]:
    # Critério simples: menor desvio em TDS, penalizando falta de TEMP_OK.
    best_mode = None
    best_score = None

    for r in results:
        tds_stdev = r["tds_stats"]["stdev"]
        if tds_stdev is None:
            continue
        penalty = (1.0 - r["temp_ok_ratio"]) * 100.0
        score = tds_stdev + penalty
        if best_score is None or score < best_score:
            best_score = score
            best_mode = r["mode"]

    if best_mode is None:
        return -1, "Sem dados suficientes para recomendar."

    return best_mode, (
        f"Modo recomendado: {best_mode} ({MODE_NAMES.get(best_mode)}), "
        "pois apresentou melhor estabilidade de TDS com menor penalidade de TEMP_OK."
    )


def main():
    parser = argparse.ArgumentParser(description="Diagnóstico comparativo de leituras da placa.")
    parser.add_argument("--port", required=True, help="Porta serial (ex.: /dev/ttyUSB0)")
    parser.add_argument("--baud", type=int, default=115200, help="Baud rate (padrão 115200)")
    parser.add_argument("--seconds", type=int, default=30, help="Segundos por modo")
    parser.add_argument("--warmup", type=float, default=2.0, help="Aquecimento por modo")
    parser.add_argument(
        "--modes",
        default="0,1,2,3,4",
        help="Lista de modos separados por vírgula (ex.: 0,2,3)",
    )
    args = parser.parse_args()

    modes = [int(m.strip()) for m in args.modes.split(",") if m.strip()]

    print(f"Conectando em {args.port} @ {args.baud}...")
    with serial.Serial(args.port, args.baud, timeout=1.5) as ser:
        time.sleep(2.0)  # reset da placa
        ser.reset_input_buffer()

        results = []
        for mode in modes:
            if mode not in MODE_NAMES:
                print(f"Modo {mode} ignorado (inválido).")
                continue
            print(f"\nExecutando modo {mode} ({MODE_NAMES[mode]}) por {args.seconds}s...")
            result = run_mode_test(ser, mode, args.seconds, args.warmup)
            results.append(result)
            print_result(result)

        best_mode, recommendation = pick_recommendation(results)
        print("\n=== RECOMENDACAO ===")
        print(recommendation)
        if best_mode >= 0:
            ser.write(f"MODE={best_mode}\n".encode())
            ser.flush()
            print(f"Firmware deixado no modo recomendado: {best_mode}")


if __name__ == "__main__":
    main()

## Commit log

2026-04-09 feat(cad): revisar saída do display OLED e fixação na tampa
    [caixa_iara_v1.scad]
2026-04-09 feat(cad): gerar STL prontos para impressão e perfil PETG Creality Hi
    [caixa_iara_v1_base.stl, caixa_iara_v1_tampa.stl]
2026-04-09 fix(cad): corrigir saídas de cabos e adicionar preview visual no OpenSCAD
    [caixa_iara_v1.scad, caixa_iara_v1_base.stl, caixa_iara_v1_tampa.stl]
2026-04-09 fix(cad): ajustar saída TDS 5x7 e cabo de temperatura 4mm
    [caixa_iara_v1.scad, caixa_iara_v1_base.stl, caixa_iara_v1_tampa.stl]
